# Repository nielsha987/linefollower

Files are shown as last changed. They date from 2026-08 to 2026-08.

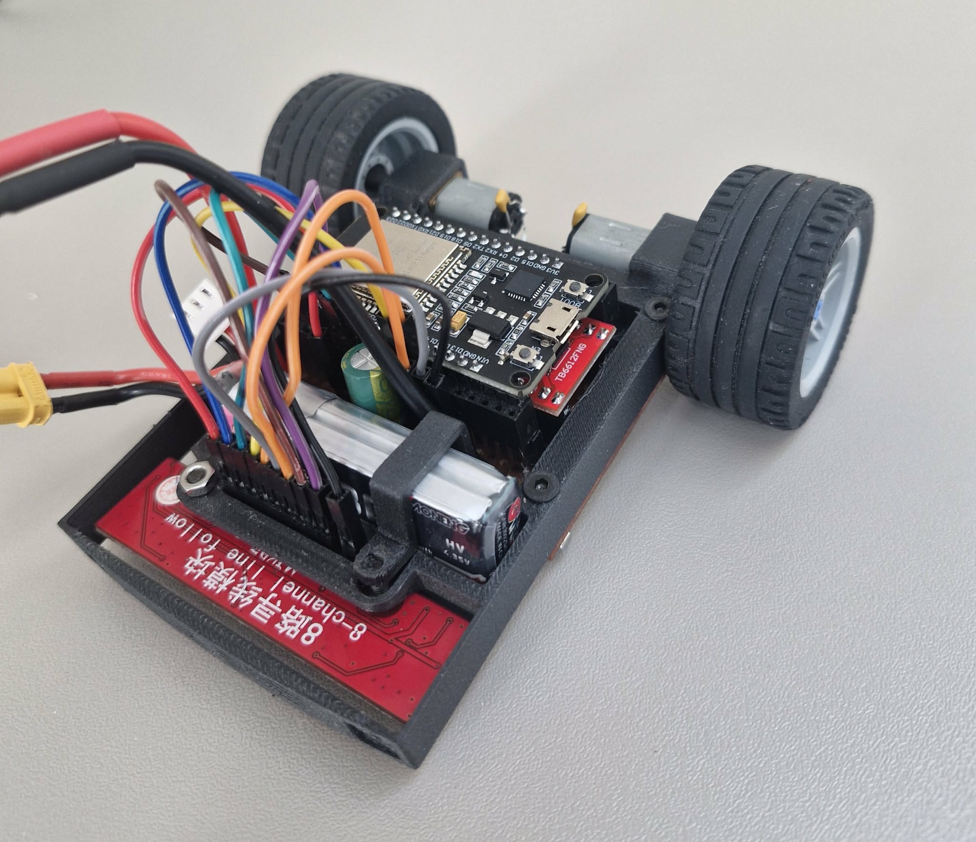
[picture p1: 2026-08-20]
images/4d00b242-ace5-4727-a8fa-824ff54b394b.jpg

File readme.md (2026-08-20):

# LineFollower

4d00b242-ace5-4727-a8fa-824ff54b394b

## specifications

microcontroller: ESP32 Wi-Fi en Bluetooth Board - CP2102

motors: Aslong JGA12-N20-30 DC-Transmissiemotor 6V - 500RPM

h-bridge:TB6612FNG Easy Motor Driver

sensors: 8x IR Lijn Tracking Module

batteries: GAONGNENG GNB LiHV 2s

wireless communication: bleutooth

distance sensor - motors: 90mm

weight: 150G

speed: /

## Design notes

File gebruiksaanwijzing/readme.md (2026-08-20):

# Gebruiksaanwijzing LineFollow Robot

Deze pagina beschrijft hoe je de LineFollow Robot veilig gebruikt, verbindt met de applicatie, kalibreert en instelt.

---

## 1. Batterij opladen en vervangen

De robot gebruikt een LiPo HV 2S-batterij met een volledig geladen spanning van 8,7 V.

> ⚠️ GEVAAR: LiPo-batterijen kunnen zeer brandgevaarlijk zijn bij verkeerd gebruik of beschadiging.

### Belangrijke veiligheidsregels

- Gebruik enkel een geschikte LiPo-lader die door de fabrikant wordt aanbevolen.
- Laad de batterij altijd op met de balansstekker aangesloten.
- Hierdoor worden de afzonderlijke cellen correct geladen en wordt celonbalans vermeden.
- Koppel de batterij altijd fysiek los van de robot tijdens het opladen.
- Sluit nooit gelijktijdig de batterij en de USB-kabel van de computer aan op de robot.

### Robot inschakelen

De robot wordt ingeschakeld door de batterij aan te sluiten.

### Robot uitschakelen

Koppel de batterij fysiek los van de robot.

---

## 2. Draadloze communicatie

De robot communiceert via Bluetooth met de bijbehorende GUI-applicatie.

Hierdoor zijn geen handmatige seriële commando's nodig.

### Verbinding maken

1. Zorg dat de robot is ingeschakeld en de batterij aangesloten is.
2. Open de applicatie.
3. Ga naar de Connectie Tab.
4. Druk op Verbinden.
5. Wanneer de verbinding gelukt is, geeft de applicatie de status Verbonden weer.

### Verbinding verbreken

De Bluetoothverbinding kan op verschillende manieren worden verbroken:

- Druk in de applicatie op Verbreken.
- Sluit de applicatie.
- Koppel de batterij los van de robot.

---

## 3. Applicatie

De applicatie bestaat uit vier tabs.

### 3.1 Connectie Tab

De Connectie Tab wordt gebruikt om de Bluetoothverbinding met de robot te beheren.

Beschikbare functies:

- Verbinden
- Verbreken
- Weergave van de huidige verbindingsstatus

---

### 3.2 Sensoren Tab

De Sensoren Tab toont de live waarden van de lijnsensoren.

De sensorwaarden worden weergegeven in de vorm van een balkgrafiek.

Hierdoor kan eenvoudig gecontroleerd worden:

- welke sensoren wit detecteren;
- welke sensoren zwart detecteren;
- of alle sensoren correct functioneren;
- of de kalibratie correct is uitgevoerd.

Vanuit deze tab kan ook de kalibratie van wit en zwart worden uitgevoerd.

---

### 3.3 Settings Tab

De Settings Tab wordt gebruikt om de robot te starten, stoppen en configureren.

#### Start

Met Start wordt de automatische lijnvolgroutine gestart.

De robot gebruikt hierbij de PID-regeling om de zwarte lijn te volgen.

#### Stop

Met Stop wordt de robot onmiddellijk gestopt en wordt de PID-regeling uitgeschakeld.

#### Parameters

| Parameter | Functie |
|---|---|
| Basis Snelheid | Basissnelheid van de robot, tussen 0 en 255 |
| Kp | Proportionele parameter van de PID-regelaar |
| Ki | Integrerende parameter van de PID-regelaar |
| Kd | Differentiërende parameter van de PID-regelaar |
| Minimaal contrast | Minimaal verschil tussen zwart en wit voordat de robot de lijn als verloren beschouwt |
| Laagdoorlaatfilter | Filter op de berekende positie van de lijn |

#### Testmodus – ZQSD

De robot kan vanuit de Settings Tab ook manueel worden bestuurd met de ZQSD-toetsen.

Hiermee kunnen de motoren afzonderlijk getest en bediend worden.

De testmodus is onder andere handig om:

- de motoren te controleren;
- de draairichting te controleren;
- de robot handmatig te verplaatsen;
- de robot na lijnverlies opnieuw op de lijn te plaatsen.

> Belangrijk: manuele besturing is enkel mogelijk wanneer de gebruiker zich in de Settings Tab bevindt.

---

### 3.4 Plot Tab

De Plot Tab wordt gebruikt om de prestaties van de robot na een run te analyseren.

Hier kunnen de geregistreerde gegevens van een uitgevoerde run bekeken worden.

De grafieken kunnen gebruikt worden om het gedrag van de robot en de PID-regeling te beoordelen.

---

## 4. Kalibratie

Kalibratie is het proces waarbij de sensorwaarden softwarematig worden genormaliseerd.

Het doel hiervan is:

- een zo groot mogelijk onderscheid te verkrijgen tussen wit en zwart;
- verschillen tussen de individuele sensoren te compenseren;
- een betrouwbare lijnpositie te kunnen berekenen.

> ⚠️ Belangrijk: voer de kalibratie uit op hetzelfde witte en zwarte materiaal dat ook tijdens de uiteindelijke run gebruikt wordt.

### 4.1 Verbinding maken

1. Schakel de robot in.
2. Open de applicatie.
3. Ga naar de Connectie Tab.
4. Verbind met de robot.
5. Ga daarna naar de Sensoren Tab.

### 4.2 Kalibratie WIT

1. Plaats de robot zodat alle sensoren boven de witte achtergrond van het parcours staan.
2. Controleer in de Sensoren Tab of de sensorbalken een lage waarde weergeven.
3. Druk op Kalibreer WIT.

De gemeten waarden worden gebruikt als referentiewaarden voor wit.

### 4.3 Kalibratie ZWART

1. Plaats de robot zodat de sensoren boven de zwarte lijn staan.
2. Controleer in de Sensoren Tab of de sensorbalken een hoge waarde weergeven.
3. Druk op Kalibreer ZWART.

De gemeten waarden worden gebruikt als referentiewaarden voor zwart.

---

## 5. Aanbevolen instellingen

De robot rijdt stabiel met volgende parameters:

| Parameter | Waarde |
|---|---:|
| Kp | 7 |
| Ki | 0 |
| Kd | 0 |
| Speed | 140 |

Speed 140 is de basissnelheid van de robot.

Deze waarden kunnen verder worden aangepast afhankelijk van het parcours en het gewenste rijgedrag.

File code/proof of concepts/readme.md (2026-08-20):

# Proof of Concepts

Een proof of concept is een combinatie van minimale hard- en software om eenvoudig aan te tonen dat iets werkt.  
Proof of concepts kunnen enerzijds als eerste poging dienen om een bepaald onderdeel van het project werkend te krijgen. Anderzijds kunnen ze tijdens het debuggen van het finale project dienen als test om eventuele hardware problemen te elimineren bij onduidelijke problemen.
<br />  
<br />
Een proof of concept bestaat uit
* een elektronisch schema (indien van toepassing)
* minimale code om de voorop gestelde zaken te demonstreren
* minimale uitleg / aandachtspunten
<br />
De elektronische schakelingen van de proof of concepts komen bij voorkeur overeen met deze van de uiteindelijke linefollower, zodat de code zonder aanpassingen op het finale project kan draaien.

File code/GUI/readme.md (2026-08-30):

#  GUI Applicatie

Dit project is een Python-applicatie met een GUI gebouwd met PyQt6 en is gericht op het besturen van de linefollower en dataanalyse van gereden runs

## Installatie

Volg deze stappen om het project lokaal op uw computer in te stellen en uit te voeren.

### 1. Project Klonen

Open uw commandoregel en download de code van GitHub:

```bash
git clone https://github.com/nielsha987/linefollower
cd code/GUI
```
### 2. Virtuele Omgeving Instellen (niet verplicht maar aanbevolen)

#### Maak een virtuele omgeving om ervoor te zorgen dat u systeem niet vervuilt en om conflicten te vermijden 
Creëer de omgeving:
  ```bash
  python -m venv venv
  ```
Activeer de omgeving:
  ```bash
  .\venv\Scripts\Activate
  ```
### 3. Dependencies Installeren

#### Installeer alle benodigde pakketten die in het requirements.txt bestand zijn gespecificeerd:

 ```bash
pip install -r req.txt
 ```
  Dit installeert alle vereisten, inclusief de GUI-bibliotheek (PyQt6), plotting tools (matplotlib), en seriële communicatie (pyserial).
#### De Applicatie Uitvoeren

Zodra de virtuele omgeving actief is en de installatie is voltooid, start u de applicatie met dit commando:

 ```bash
python main.py
 ```
De grafische gebruikersinterface zou nu moeten verschijnen.

### NOTE : Belangrijke Map- en Bestandsstructuur
  De applicatie is ontworpen om bepaalde bestanden en mappen automatisch aan te maken in de map waar u python main.py uitvoert.
#### 1. CSV-bestanden
      Wanneer: Als u in de GUI op de knop "Maak CSV" drukt.
     
      Locatie: Er wordt een nieuwe submap gemaakt genaamd csv_files (als deze nog niet bestaat).
     
      Doel: Alle geëxporteerde gegevens worden in deze map opgeslagen.

#### 3. Lokale Database
      Actie: De database wordt automatisch gecreëerd bij de eerste keer opstarten of wanneer een database-actie vereist is.
      
      Locatie: Het databasebestand (robot_data.db) wordt direct in de hoofdmap van de applicatie aangemaakt (naast main.py).

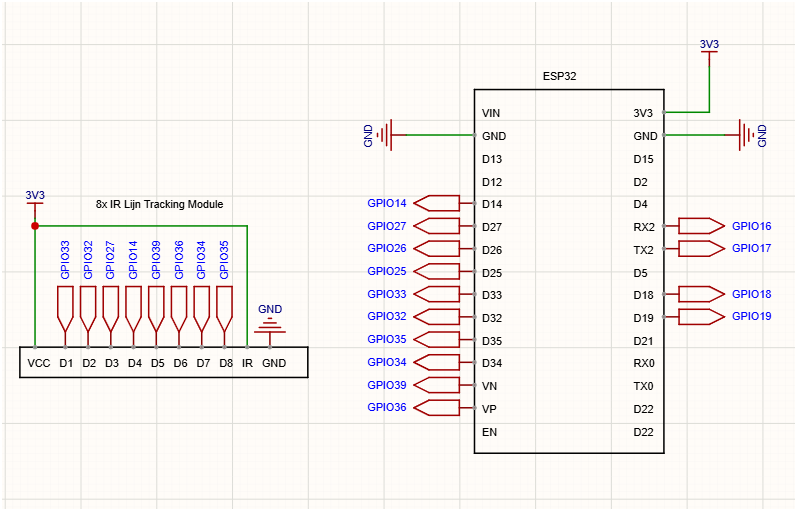
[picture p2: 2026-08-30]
code/proof of concepts/sensor/image.png

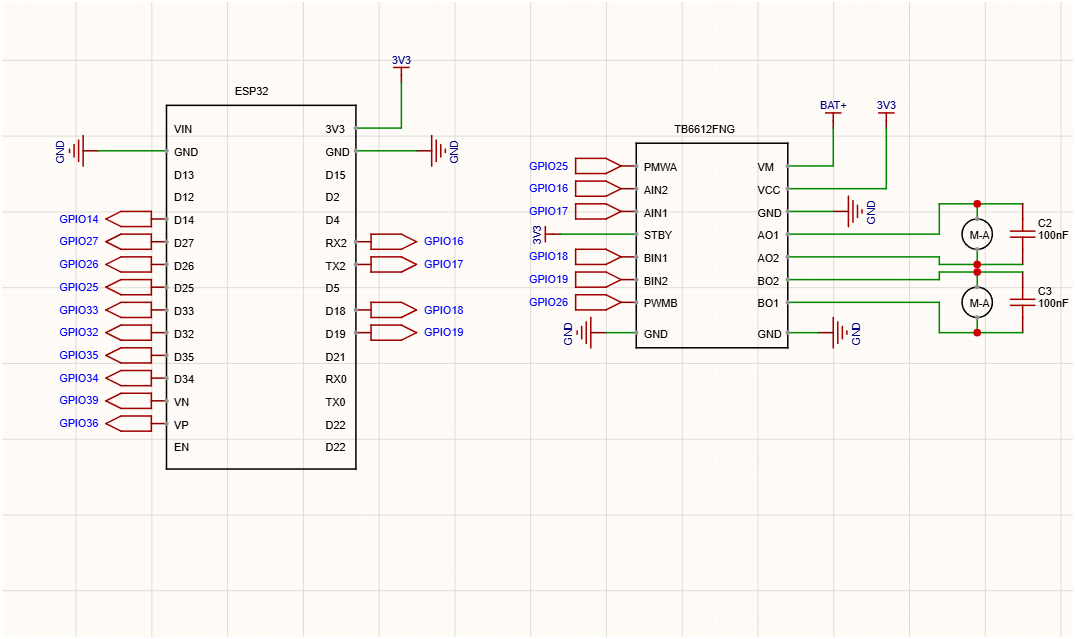
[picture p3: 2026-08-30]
code/proof of concepts/hbridge/image.png

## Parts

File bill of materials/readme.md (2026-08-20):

## bill of materials
<br />

#  BOM

| naam | omschrijving | nieuwe/recup | kostprijs/stuk | eenheid | aantal | subtotaal |
| :--- | :--- | :--- | :--- | :--- | :--- | :--- |
| 43.2 mm tire | LEGO | recup | 0.39 | €/stuk | 2 | €0.78 |
| Aslong JGA12-N20-10 | 6V 1500RPM | nieuw | 4.5 | €/stuk | 2 | €9.00 |
| GAONGNENG GNB LiHV 2s | 7.6V 300mAh 80C XT30 | nieuw | 5.36 | €/stuk | 1 | €6.21 |
| ESP32 Wi-Fi en Bluetooth Board - CP2102|microcontroller | nieuw | 9 | €/stuk | 1 | €9.00 |
| DC-DC Step-down Buck Converter | 3A - 3.3V output | nieuw | 3 | €/stuk | 1 | €3.00 |
| TB6612FNG | Easy Motor Driver | nieuw | 7 | €/stuk | 1 | €7.00 |
| 8x IR Lijn Tracking Module | 40mm Bereik | nieuw | 3.5 | €/stuk | 1 | €5 |
| chasis | 3D print.zie /mechanisch |nieuw  |  |  |  |  |
| Experimenteer printplaat | 5 x 7 cm | recup | 0.65 | €/stuk | 1 | €0.65 |
|GeeekPi 2x20 40 Pin Stacking Female Header Kit | | nieuw | 13 | €/stuk | 1 | €13 |
| Vrouwelijke Header | (Pin Len: 2 mm) | nieuw | 0.1 | €/stuk | 2 | €0.20 |
| xt30- male connector | >10 cm | nieuw | 1.75 | €/stuk | 1 | €1.75 |
| dupont draadjes |  | nieuw | 0.5 | €/stuk | 2 | €1 |

## Totaaloverzicht

| Post | Waarde |
| :--- | :--- |
| **Totale Som** | **€56,59**  |

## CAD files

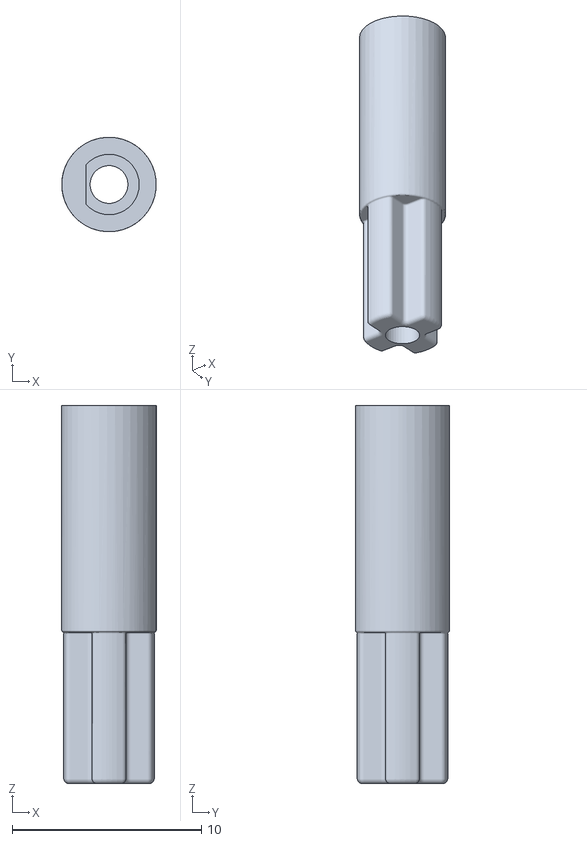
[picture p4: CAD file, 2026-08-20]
technische tekeningen/mechanisch/DnaarLegoCross.STL
5.00 x 5.00 x 20.0

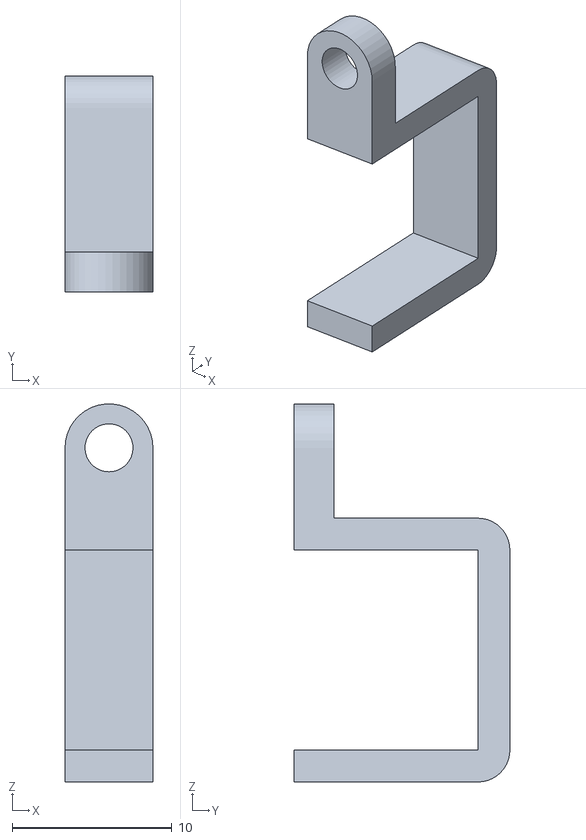
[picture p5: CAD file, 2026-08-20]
technische tekeningen/mechanisch/Batterij_Holders_V2.0.STL
5.50 x 13.5 x 23.6

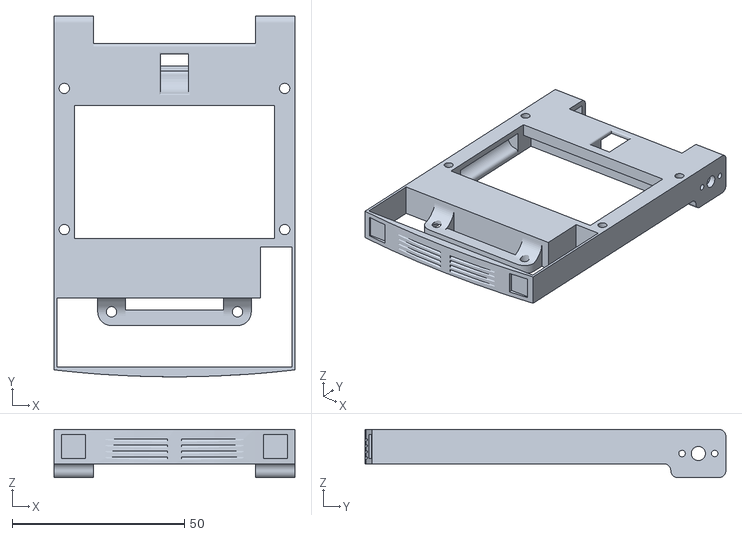
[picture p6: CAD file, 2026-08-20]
technische tekeningen/mechanisch/Frame.STL
70.0 x 104.8 x 14.0

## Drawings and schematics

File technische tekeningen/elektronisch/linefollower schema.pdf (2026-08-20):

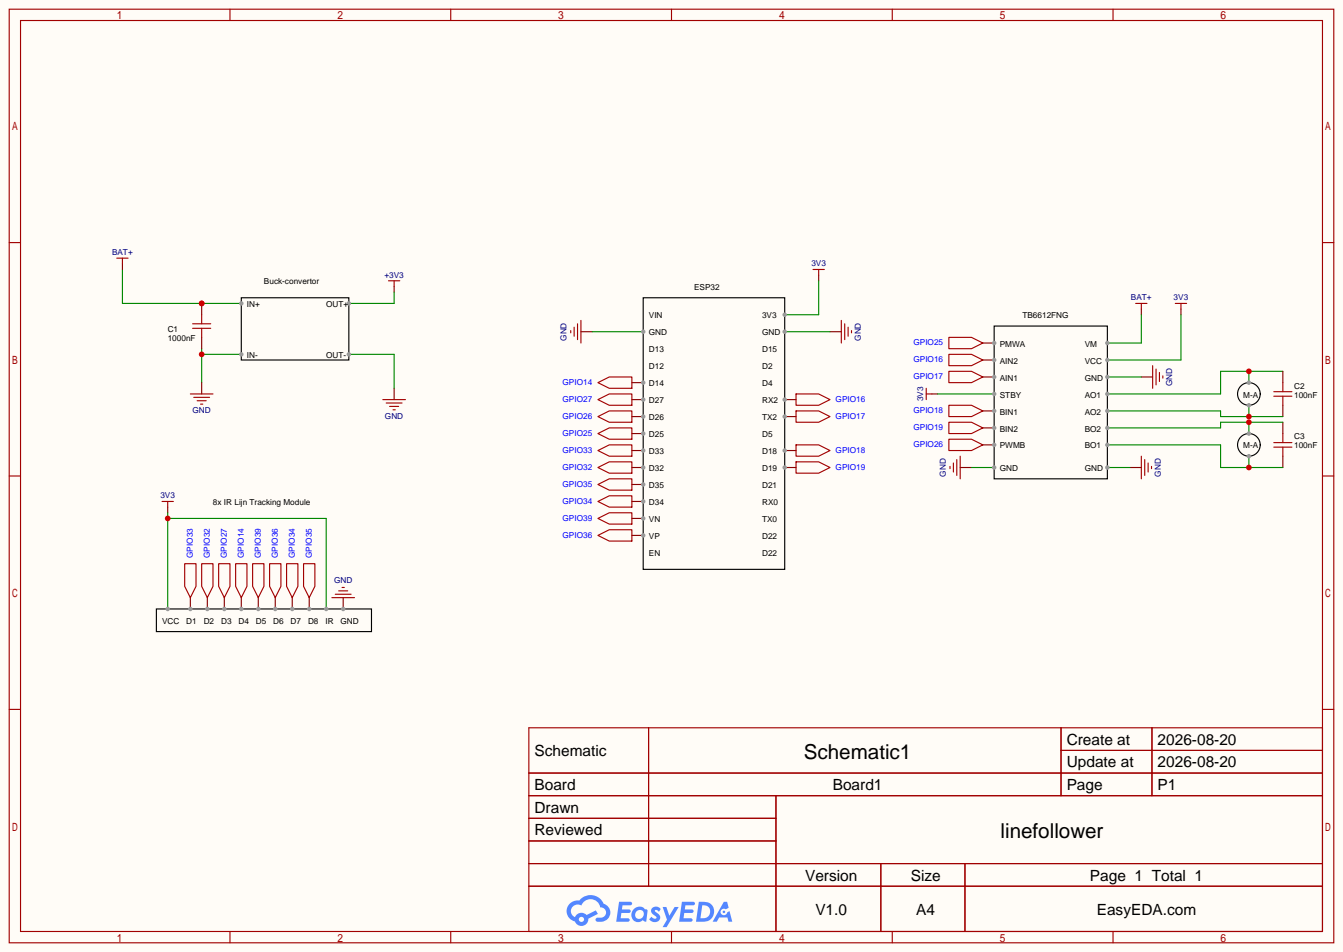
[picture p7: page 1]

8x IR Lijn Tracking Module

VCC D1 D2 D3 D4 D5 D6 D7 D8 IR GND GPIO³³ GPIO³² GPIO²⁷ GPIO¹⁴ GPIO³⁹ GPIO³⁶ GPIO³⁴ GPIO³⁵

Schematic | Schematic1 | Create at | 2026-08-20

Update at | 2026-08-20

Board | Board1 | Page | P1
Drawn | | linefollower
Reviewed

Version | Size | Page 1 Total 1
V1.0 | A4 | EasyEDA.com

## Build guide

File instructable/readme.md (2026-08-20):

# Instructable

### stap 1 Componenten Bestellen en 3D-printen
bestel alle componenten uit de bill of materials
3D-print de mechanische componenten die beschreven staan in de map

### stap 2 header pins op het soldeer board solderen
Soldeer de header pins aan alle componenten

### stap 3 voorbereiden van de print
1. Soldeer de vrouwelijke headerpinnen op de perforatieprint. Laat voldoende ruimte voor het 3D-geprinte frame.
2. Soldeer de voedingskabel voor de batterij op de + en - aansluiting van de print.
3. Soldeer een condensator van 1000 µF parallel over de batterijvoeding.
4. Soldeer kleine condensatoren over beide motoren om storingen en spanningspieken te beperken.
5. Soldeer draden aan de motoren en leid deze via het voorziene poortje naar de printplaat.
6. Maak aan de onderzijde van de print de nodige verbindingen tussen de ESP32, motor driver en buck converter.

### stap 4 montage van de printplaat aan het frame
Plaats het perforatieprintje (met de motoren) onder het 3D-geprinte frame.

Lijn de gaten uit.

Schroef het geheel aan elkaar met de bouten en moeren.

### stap 5 Montage van de Line Follower Sensor
laats de 8-channel Line Follow sensor in de voorziene opening aan de voorkant van het frame.

plaats de batterijhouder juist

Schroef deze vast met de bijbehorende bouten en moeren.

### stap 6 Plaatsen van de Hoofdcomponenten
Plaats de extender female pinnen op de reeds gesoldeerde female pinnen van het perforatieprintje.

Plaats de ESP-32 op de extender pinnen. Zorg dat de ESP correct is georiënteerd.

Plaats de Motor Driver (rood) en de Buck Converter (blauw) op de daarvoor bestemde plekken op de printplaat.

### stap 7 Aansluiten van de Sensoren
Neem Dupont draadjes en steek die in de overgebleven open female headers

Maak de verbinding tussen deze headers en de pinnen van de 8-channel Line Follow sensor volgens het schema.

### stap 8 Finaliseren en Klaar voor Software

Bevestig de wielen op de motorassen.

Sluit de batterij aan op de XT30-connector.

De robot is nu mechanisch en elektrisch geassembleerd.

### Stap 9 Voorbereiding en installatie van de code

1. Zorg dat Arduino IDE geïnstalleerd is en dat de ESP32 Board Support Package  is toegevoegd.
2. Ga naar de map `code/finaal/` en download alle bestanden uit deze map.
3. Plaats alle bestanden samen in één map op uw computer. De mapnaam moet overeenkomen met de naam van het `.ino`-bestand.
4. Open het `.ino`-bestand in Arduino IDE.

### Stap 10: Compileren en uploaden naar de ESP32

1. Verbind de ESP32 met de computer via USB.
2. Selecteer in Arduino IDE het juiste board, bijvoorbeeld `ESP32 Dev Module`.
3. Selecteer de juiste seriële poort.
4. Klik op Uploaden om de code naar de ESP32 te sturen.

### Stap 11: Veiligheidswaarschuwingen

- Sluit nooit tegelijk de batterij en de USB-kabel aan op de robot.
- Gebruik de USB-aansluiting enkel voor programmeren.
- Voed de motoren altijd via de externe batterij en de motor driver.

### Stap 12: Installatie van de GUI

Volg het stappenplan in `code/GUI/readme.md` om de bijbehorende gebruikersinterface op de computer te installeren.

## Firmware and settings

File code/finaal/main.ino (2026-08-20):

#include <BluetoothSerial.h>
#include <TB6612.h>
#include <EEPROM.h>

BluetoothSerial SerialBT;

#define EEPROM_SIZE 512 // aantal bytes
#define EEPROM_FIRST_CHECK 0xBEEDCAFE // voor eerste flash van ESP
#define CHECK_ADDR 500 // Oude Check Adres, niet meer nodig maar voor backward compatibility


// DEBUG Toggle
#define DEBUG 0  // 0 = off , 1 = on 
#if DEBUG 
  #define Debug_println(x) Serial.println(x)
  #define Debug_print(x) Serial.print(x)
#else 
  #define Debug_print(x)
  #define Debug_println(x)
#endif

// --- STRUCTUREN ---

struct Motor {
  uint8_t nummer;
  int speed; // snelheid van motor 
  const uint8_t pwm;
  const uint8_t in1; // in 1 pin
  const uint8_t in2; // in 2 pin
};

struct Sensor {
  const char* naam;
  const uint8_t pin; 
  uint16_t zwart; // uit eeprom
  uint16_t wit; // uit eeprom
  int waarde; //raw
  int norm;  // genormaliseerd
};

struct pidController {
  float kp, ki, kd;
  float error;
  float lastError;
  float integral;
  float derivative;
  float output;
};

struct timer{
  uint32_t time;
  const uint16_t interval;
};

struct varIntervalTimer{
  uint32_t time;
  uint16_t interval;
};

struct status{
  bool run;
  bool verbonden;
  bool inSyncGestuurd;
  bool eenLijn;
};

struct ConfigParams {
  float kp, ki, kd;
  uint16_t power;
  uint16_t interval; // calc.interval
  float filterAlpha;
  uint16_t contrastDrempel;
};


Sensor sensoren[] = {
  {"DP_1", 33, 4095, 0, 0},
  {"DP_2", 32, 4095, 0, 0},
  {"DP_3", 27, 4095, 0, 0},
  {"DP_4", 14, 4095, 0, 0},
  {"DP_5", 39, 4095, 0, 0},
  {"DP_6", 36, 4095, 0, 0},
  {"DP_7", 34, 4095, 0, 0},
  {"DP_8", 35, 4095, 0, 0},
};

Motor motoren[]{
  {1, 0, 25, 17, 16},
  {2, 0, 26, 18, 19},
};

status robot;

pidController pid; // Operationeel PID struct
ConfigParams params; // EEPROM opslag struct

varIntervalTimer calc{0,2000};
varIntervalTimer send{0,200}; // interval voor telementry data 

timer ping{0,20000}; // vaste interval timer in millis onderhoud bt connectie
timer eepromCommitTimer{0, 2000}; //  Debounce timer voor EEPROM commit

const uint8_t AANTAL_SENSOREN = sizeof(sensoren) / sizeof(sensoren[0]);
const uint8_t AANTAL_MOTOREN = sizeof(motoren) / sizeof(motoren[0]);

uint16_t power = 0; // Gebruikt nu params.power, maar behouden voor backward compatibility in updatePID.
float filterAlpha = 0.8f; // Gebruikt nu params.filterAlpha
uint16_t contrastDrempel = 250; //  Gebruikt nu params.contrastDrempel

float position = 0;
float filterPosition = 0;

static unsigned long lastTime = 0; // Voor PID Delta t
bool telementry = true; // normaal telementry aan als GUI opstart
bool vorigeLijnStatus = true;
bool configChanged = false; //"Dirty" flag voor EEPROM

MotorDriver motors(
  motoren[0].pwm, motoren[0].in1, motoren[0].in2, 
  motoren[1].pwm, motoren[1].in1, motoren[1].in2
);

// Dynamische EEPROM Adressen 
struct eepromOffsets{
  const uint16_t checkAddr = 0;
  const uint16_t paramsAddr = sizeof(EEPROM_FIRST_CHECK); // Start direct na de 4-byte check
  const uint16_t witAddr = paramsAddr + sizeof(ConfigParams);
  const uint16_t zwartAddr = witAddr + (AANTAL_SENSOREN * sizeof(uint16_t));
};

eepromOffsets adressen; // Adressen struct

void setup() {
  Serial.begin(115200);
  SerialBT.begin("LineFollow_V2"); // init bt
  EEPROM.begin(EEPROM_SIZE);
  motors.motor_init();   // init motordriver

  // first flash veilige waarden zetten 
  uint32_t first;
  EEPROM.get(adressen.checkAddr, first); // Gebruik nieuwe checkAddr
  
  if(first != EEPROM_FIRST_CHECK){
    Debug_println("Eerste flash of EEPROM gereset. Schrijf veilige defaults.");
    
    // Default sensorwaarden
    for (uint8_t i = 0; i < AANTAL_SENSOREN; i++) {
      // Gebruik nieuwe adressen
      EEPROM.put(adressen.witAddr + i * sizeof(uint16_t), sensoren[i].wit);
      EEPROM.put(adressen.zwartAddr + i * sizeof(uint16_t), sensoren[i].zwart);
    }

    // Default ConfigParams struct
    ConfigParams defaultParams = {
      1.0f, 0.0f, 0.0f, // kp, ki, kd
      50, // power
      2000, // calc.interval
      0.8f, // filterAlpha
      250 // contrastDrempel
    };
    EEPROM.put(adressen.paramsAddr, defaultParams); // Schrijf het hele blok ConfigParams

    first = EEPROM_FIRST_CHECK;
    EEPROM.put(adressen.checkAddr, first);
    EEPROM.commit();
  }
  
  //Lees EEPROM waarden in struct

  //PID & Config
  EEPROM.get(adressen.paramsAddr, params);
  
  pid.kp = params.kp; 
  pid.ki = params.ki; 
  pid.kd = params.kd;
  power = params.power;
  calc.interval = params.interval;
  filterAlpha = params.filterAlpha;
  contrastDrempel = params.contrastDrempel;

  //Sensor Normalisatie waarden
  for (uint8_t i = 0; i < AANTAL_SENSOREN; i++) {
    EEPROM.get(adressen.witAddr + i * sizeof(uint16_t), sensoren[i].wit);
    EEPROM.get(adressen.zwartAddr + i * sizeof(uint16_t), sensoren[i].zwart);
  }
}


void loop() {
  uint32_t nuMillis = millis();
  uint32_t nuMicros = micros();
  
  // BT Altijd actieve checks
  if (SerialBT.available()) {
    String msg = SerialBT.readStringUntil('\n');
    msg.trim();
    // Debug_println("Ontvangen: " + msg);

    // PING / PONG handshake
    if (msg == "PING") {
      SerialBT.println("PONG");
      robot.verbonden = true;
      ping.time = millis();
    }
    // Verwerk JSON berichten
    else if (msg.startsWith("{") && msg.endsWith("}")) {

      // Essentiële commando's (run, telem) ALTIJD  verwerken
      if (msg.indexOf("\"run\"") != -1)  {
        bool newRunStatus = msg.indexOf("\"true\"") != -1;
        robot.run = newRunStatus; // Update status

        // Als de nieuwe status STOP is (false), zet de motoren struct direct stil
        if (!robot.run) { 
          motoren[0].speed = 0; // Zet motoren stil in struct
          motoren[1].speed = 0; // Zet motoren stil in struct
        }
      }
      
      // Telementry aan/uit 
      else if (msg.indexOf("\"telem\"") != -1) {
        telementry = msg.indexOf("\"true\"") != -1;
      }
      
      // Configuratie en manuele commando's verwerken ALLEEN als de robot.run = false is
      else if (!robot.run) {
        if (msg.indexOf("\"motor\"") != -1) handleManMotorSpeed(parseMotorJson(msg));
        else if (msg.indexOf("\"pid\"") != -1) handlePid(msg);
        else if (msg.indexOf("\"interval\"") != -1) handleInterval(msg);
        else if (msg.indexOf("\"speed\"") != -1) handleSpeed(msg);
        else if (msg.indexOf("\"filter\"") != -1) handleFilter(msg);
        else if (msg.indexOf("\"contrast\"") != -1) handleContrast(msg);
        else if (msg.indexOf("\"calib\"") != -1) {
          if (msg.indexOf("\"white\"") != -1) calibWit();
          else if (msg.indexOf("\"black\"") != -1) calibZwart();
        }
      }
    }
  }

  // EEPROM DEBOUNCED COMMIT LOGICA 
  // Dit zorgt ervoor dat meerdere config wijzigingen in één keer worden weggeschreven na een pauze van 2s.
  if (configChanged && (nuMillis - eepromCommitTimer.time >= eepromCommitTimer.interval)) {
    ConfigParams oldParams;
    EEPROM.get(adressen.paramsAddr, oldParams);
    
    // Gebruik memcmp om te controleren of er bytes zijn veranderd
    if (memcmp(&oldParams, &params, sizeof(ConfigParams)) != 0) {
      EEPROM.put(adressen.paramsAddr, params); // Schrijf het hele blok
      EEPROM.commit(); 
      Debug_println("EEPROM Config parameters committed na debouncing.");
    }
    
    configChanged = false; // Reset de flag
  }

  // TIMEOUT CONTROLE
  if (robot.verbonden && (nuMillis - ping.time > ping.interval)) {
    robot.verbonden = false;
    robot.inSyncGestuurd = false;
    Debug_println("Verbinding verbroken");
  }

  // TELEMENTRY VERZENDEN
  if(robot.verbonden && telementry){
    if (nuMillis - send.time >= send.interval) {
      send.time = nuMillis;
      // Stuur sensorwaarden, position, output
      for (uint8_t i = 0; i < AANTAL_SENSOREN; i++) {
        Sensor& s = sensoren[i];
        String json = JsonFormat(s.naam, s.norm);
        SerialBT.println(json);
      }
      String json = JsonFloatFormat("position", filterPosition);
      SerialBT.println(json);
      json = JsonFloatFormat("output", pid.output);
      SerialBT.println(json);
      
      // Stuurt eenmalig een sync bericht met de app (voor PID & power)
      if(robot.inSyncGestuurd == false && SerialBT.hasClient()){
        String json = JsonFormat("speed", power);
        SerialBT.println(json);
            
        json = JsonFormat("interval", calc.interval);
        SerialBT.println(json);
        
        json = JsonFloatFormat("filter", filterAlpha);
        SerialBT.println(json);
        
        json = JsonFormat("contrast", contrastDrempel);
        SerialBT.println(json);
            
        char c[512]; 
        sprintf(c, "{\"pid\": {\"kp\": %.2f, \"ki\": %.2f, \"kd\": %.2f}}", pid.kp, pid.ki, pid.kd);
        json = String(c);
        SerialBT.println(json);
            
        robot.inSyncGestuurd = true; // zet in sync flag hoog 
      }
    }
  }

  // --- REGELSYCLUS (DO CYCLUS) ---
  if (nuMicros - calc.time >= calc.interval){
    calc.time = nuMicros;
    unsigned long start = micros();
    
    // normaliseer sensor waarden 
    sensorNormalisatie();

    // Bepaal de zwaarste sensor
    uint8_t index = 0;
    for (uint8_t i = 1 ; i < AANTAL_SENSOREN; i++){
      if(sensoren[i].norm > sensoren[index].norm) index = i;
    }

    // controle op lijn 
    bool huidigeLijnStatus = geenLine(contrastDrempel);
    
    // Op positieve edge (van 'lijn gevonden' naar 'geen lijn') de motoren en run stil leggen
    if  (huidigeLijnStatus == true && vorigeLijnStatus == false){ 
      robot.run = false;
      motoren[0].speed = 0; // Zet motoren stil in struct
      motoren[1].speed = 0; // Zet motoren stil in struct
      
      // Verzend feedback naar GUI
      if (robot.verbonden) {
        SerialBT.println("{\"status\": \"LOST_LINE\"}"); 
      }
    }

    vorigeLijnStatus =  huidigeLijnStatus;

    // Kwadratische interpolatie voor positiebepaling
    float s1 = sensoren[index].norm;
    float s0;
    if (index == 0) {
        s0 = 0.0f; // Virtuele sensor 0
    } else {
        s0 = sensoren[index - 1].norm;
    }

    float s2;
    if (index == AANTAL_SENSOREN - 1) {
        s2 = 0.0f; // Virtuele sensor 0
    } else {
        s2 = sensoren[index + 1].norm;
    }

    float offset = 0.0f;
    float denom = (s2 + s0) - 2.0f * s1;
    if (fabs(denom) > 0.001f) {
        offset = 0.5f * (s2 - s0) / denom;
    }

    float mid = (float)index + offset;
    float center = (AANTAL_SENSOREN - 1) / 2.0f;
    float scale = 60.0f / (AANTAL_SENSOREN - 1);
    position = (mid - center) * scale;
    
    // Laag doorlaatfilter (Gebruikt nu filterAlpha)
    filterPosition = (1.0f - filterAlpha) * filterPosition + filterAlpha * position;

    // PID-controle
    if (robot.run) {
      updatePID(filterPosition, power);
    } 

    // Aansturen van motoren (Single Point of Control)
    motors.set_speed(motoren[0].speed, motoren[1].speed);

    unsigned long end = micros();
  }
}


// return true als geen lijn , false als wel lijn 
bool geenLine(int contrastDrempel) { 
  int minWaarde = sensoren[0].norm;
  int maxWaarde = sensoren[0].norm;
    
  for (uint8_t i = 1; i < AANTAL_SENSOREN; i++) { 
    if(sensoren[i].norm > maxWaarde) maxWaarde = sensoren[i].norm;
    if(sensoren[i].norm < minWaarde) minWaarde = sensoren[i].norm; 
  }

  int contrast = maxWaarde - minWaarde;
  if (contrast < contrastDrempel) {
      return true; // Contrast te klein = GEEN LIJN 
  } 
  else { 
      return false;
  } 
}

String JsonFormat(const char* naam, int waarde){
  char c[100];
  sprintf(c, "{\"%s\": %d}", naam , waarde);
  return String(c);
}

String JsonFloatFormat(const char* naam, float waarde) {
  char c[100];
  sprintf(c, "{\"%s\": %.2f}" , naam , waarde);
  return String(c);
}

// markeert de configuratie als 'dirty' om EEPROM commit te triggeren
// dirty betekent dat de waarde in RAM niet gelijk is aan de waarde in EEPROM
// we markeren dat er een configchange moet gebeuren maar in de loop wachten we
// pushen we de verandering maar om de 2s om EN niet als robot.run true is 
void markConfigAsDirty() {
  configChanged = true;
  eepromCommitTimer.time = millis(); // Reset de timer
}

// sensor calibratie witte waarden 
void calibWit() {
  for (uint8_t i = 0; i < AANTAL_SENSOREN; i++) {
    uint16_t value = analogRead(sensoren[i].pin);
    sensoren[i].wit = value;
    int address = adressen.witAddr + i * sizeof(uint16_t);
    EEPROM.put(address, value);
  }
  EEPROM.commit();
  Debug_println("Witte kalibratie opgeslagen");
}

// sensor calibratie zwarte waarden 
void calibZwart() {
  for (uint8_t i = 0; i < AANTAL_SENSOREN; i++) {
    uint16_t value = analogRead(sensoren[i].pin);
    sensoren[i].zwart = value;
    int address = adressen.zwartAddr + i * sizeof(uint16_t);
    EEPROM.put(address, value);
  }
  EEPROM.commit();
  Debug_println("Zwarte kalibratie opgeslagen");
}

void sensorNormalisatie() {
  for (uint8_t i = 0; i < AANTAL_SENSOREN; i++) {
    Sensor& s = sensoren[i];
    int reading = analogRead(s.pin);
    s.waarde = reading;
    s.norm = map(s.waarde,s.wit,s.zwart,0,4095);
  }
}

void updatePID(float position, int baseSpeed) {
  unsigned long now = millis();
  float dt = (float)(now - lastTime) / 1000.0f;
  lastTime = now;
  
  pid.error = -position;
  
  // I-term 
  pid.integral += pid.error * dt;
  pid.integral = constrain(pid.integral, -1000, 1000);

  // D-term
  if (dt > 0.0001f) { 
    pid.derivative = (pid.error - pid.lastError) / dt;
  } else {
    pid.derivative = 0.0f;
  }
  pid.lastError = pid.error;
  
  // PID berekening
  pid.output = pid.kp * pid.error
             + pid.ki * pid.integral
             + pid.kd * pid.derivative;
  pid.output = constrain(pid.output, -510, 510);

  int powerRight = constrain(baseSpeed - pid.output, -255, 255);
  int powerLeft  = constrain(baseSpeed + pid.output, -255, 255);

  motoren[0].speed = powerLeft;
  motoren[1].speed = -powerRight;
}

// CONFIG HANDLERS 
void handlePid(const String& msg) {
  params.kp = haalJsonWaarde(msg, "kp").toFloat();
  params.ki = haalJsonWaarde(msg, "ki").toFloat();
  params.kd = haalJsonWaarde(msg, "kd").toFloat();

  // Update operationele PID struct direct in RAM
  pid.kp = params.kp; pid.ki = params.ki; pid.kd = params.kd;

  markConfigAsDirty();
}

void handleInterval(const String& msg) {
  params.interval = haalJsonWaarde(msg, "interval").toInt();
  // Update operationele variabele
  calc.interval = params.interval; 
  
  markConfigAsDirty();
}

void handleSpeed(const String& msg) {
  params.power = constrain(haalJsonWaarde(msg, "speed").toInt(), 0, 255);
  // Update operationele variabele
  power = params.power; 
  
  markConfigAsDirty();
}

void handleFilter(const String& msg) {
  params.filterAlpha = constrain(haalJsonWaarde(msg, "filter").toFloat(), 0.0f, 1.0f);
  // Update operationele variabele
  filterAlpha = params.filterAlpha; 
  
  markConfigAsDirty();
}

void handleContrast(const String& msg) {
  params.contrastDrempel = constrain(haalJsonWaarde(msg, "contrast").toInt(), 0, 4095);
  // Update operationele variabele
  contrastDrempel = params.contrastDrempel; 
  
  markConfigAsDirty();
}

// JSON PARSERS
String haalJsonWaarde(const String& msg, const String& key) {
  int keyIndex = msg.indexOf("\"" + key + "\"");
  if (keyIndex == -1) return "";

  int colonIndex = msg.indexOf(":", keyIndex);
  if (colonIndex == -1) return "";
  int commaIndex = msg.indexOf(",", colonIndex);
  if (commaIndex == -1) commaIndex = msg.indexOf("}", colonIndex);

  if (commaIndex == -1) return "";
  String value = msg.substring(colonIndex + 1, commaIndex);
  value.trim();
  value.replace("\"", "");
  return value;
}

// Manueel bedienen van motor terwijl motor run false is kan 
Motor parseMotorJson(const String& msg) {
  Motor m = {0, 0, 0, 0, 0};
  m.nummer = haalJsonWaarde(msg, "motor").toInt();
  m.speed  = haalJsonWaarde(msg, "value").toInt();
  return m;
}

void handleManMotorSpeed(const Motor& m){
  if (m.nummer < 1 || m.nummer > 2) return; // motor.nummer 1 of 2
  motoren[m.nummer - 1].speed = m.speed; // m.nummer 1 is array index 0 , 2 is 1 
  
  Debug_print("Motor: "); Debug_print(m.nummer);
  Debug_print(" Value: ");Debug_println(m.speed);
}

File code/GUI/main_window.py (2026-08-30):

import sys
import os
from PyQt6.QtGui import QIcon
from PyQt6.QtWidgets import QMainWindow, QTabWidget
from connect_tab import ConnectTab
from sensorplot_tab import SensorPlotTab
from motor_tab import MotorTab
from plot_tab import RunPlotTab

class MainWindow(QMainWindow):
    def __init__(self, data_manager):
        super().__init__()

        self.setWindowTitle("Mijn App")

        # Icon
        base_path = os.path.dirname(os.path.abspath(__file__))
        icon_path = os.path.join(base_path, "assets", "icon.ico")
        self.setWindowIcon(QIcon(icon_path))  
        
        self.setWindowTitle("LineFollow Configurator")
        self.setGeometry(200, 200, 800, 600)

        self.data_manager = data_manager

        self.tabs = QTabWidget()
        
        self.connect_tab = ConnectTab(self.data_manager)

        self.sensor_tab = SensorPlotTab()
        self.sensor_tab.sendData.connect(self.data_manager.send_to_esp)
        
        self.data_manager.sensor_callback = self.sensor_tab.update_values
        self.data_manager.position_callback = self.sensor_tab.update_position 
        self.data_manager.output_callback = self.sensor_tab.update_output

        self.motor_tab = MotorTab()
        self.motor_tab.sendData.connect(self.data_manager.send_to_esp)
        
        self.data_manager.pid_callback = self.motor_tab.update_pid
        self.data_manager.speed_callback = self.motor_tab.update_speed 
        self.data_manager.interval_callback = self.motor_tab.update_interval
        self.data_manager.filter_callback = self.motor_tab.update_filter
        self.data_manager.contrast_callback = self.motor_tab.update_contrast

        self.plot_tab = RunPlotTab()

        # print("sensor_callback set?", self.data_manager.sensor_callback is not None)
        self.tabs.addTab(self.connect_tab, "Connectie")
        self.tabs.addTab(self.sensor_tab, "Sensoren")
        self.tabs.addTab(self.motor_tab, "Settings")
        self.tabs.addTab(self.plot_tab, "Plot")
        self.setCentralWidget(self.tabs)
        
        # Koppel DataManager -> SensorPlotTab
        

        
     

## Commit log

2026-08-20 Add ESP32 entry to bill of materials
2026-08-20 Update bill of materials with new items and costs
2026-08-20 Create TB6612.h for motor driver class
    Added TB6612.h header file for motor driver implementation.
2026-08-20 Implement MotorDriver class for TB6612 control
2026-08-20 Create sensor test
2026-08-30 Add BluetoothManager for ESP32 connection handling
    Implement BluetoothManager class for ESP32 communication.
2026-08-30 Add DataManager class for sensor data handling
2026-08-30 Add motor control tab with GUI elements
    Implement motor control GUI with speed, PID tuning, and filter settings.
2026-08-30 Implement RunPlotTab for visualizing sensor data
2026-08-30 Rename sensor test to sensor test.ino
